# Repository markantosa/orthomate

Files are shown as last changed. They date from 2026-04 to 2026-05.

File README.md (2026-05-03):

# EPD 3D G6 — Orthomate

Battery-powered adaptive orthopedic insole controller. Redistributes plantar pressure in real-time using three micro linear stepper actuators driven by force sensor feedback. Includes a BLE companion Android app for live monitoring.

> **🏆 Winner — Top Course Project, EPD 3D Exhibition April 2026**

## Hardware at a glance

| Component | Detail |
|---|---|
| MCU | ESP32-C6 SuperMini |
| Stepper drivers | 3× TMC2209 (STEP/DIR mode, ENN hardwired LOW on PCB) |
| Actuators | 3× micro linear bipolar stepper |
| Pressure sensors | 4× FSR (R1 1kΩ + C 100nF RC filter per channel, R2 10kΩ pull-down) |
| Display | 0.91" OLED (SSD1306, I2C) |
| Charger | TP4056 Type-C |
| Boost converter | XL6009 → 5 V system rail |
| Battery | 1S LiPo 2000–3000 mAh |
| User input | 1× momentary mode button |
| BLE | NimBLE-Arduino 2.5.0 — advertises as `EPD3DG6` |

## PCB placement

Orthomate uses two custom PCBs that work together inside a modified shoe:

**Controller PCB** — mounts in a controller module. Houses the ESP32-C6, three TMC2209 stepper drivers, TP4056 charger, XL6009 boost converter, and the 20-pin connector (J9) to the insole. The LiPo battery sits alongside it.

**Insole PCB** — sits directly underfoot inside the shoe. Hosts the three FSR pressure-sensing zones (metatarsal, arch, calcaneus) and the three micro linear stepper actuator assemblies. The actuators extend upward to redistribute localised plantar pressure. Connects back to the controller PCB via a 20-pin ribbon/wire harness.

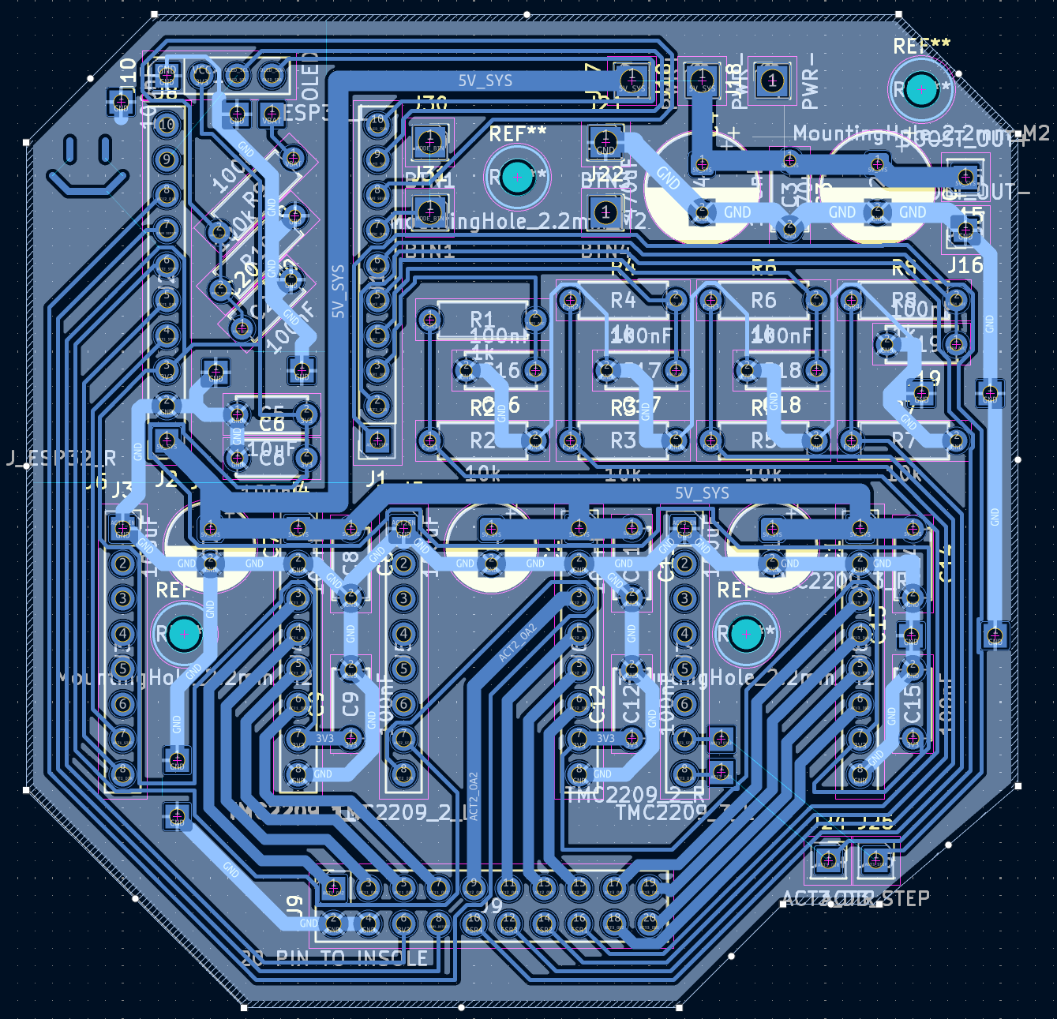
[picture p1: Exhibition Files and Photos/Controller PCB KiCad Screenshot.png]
Controller PCB
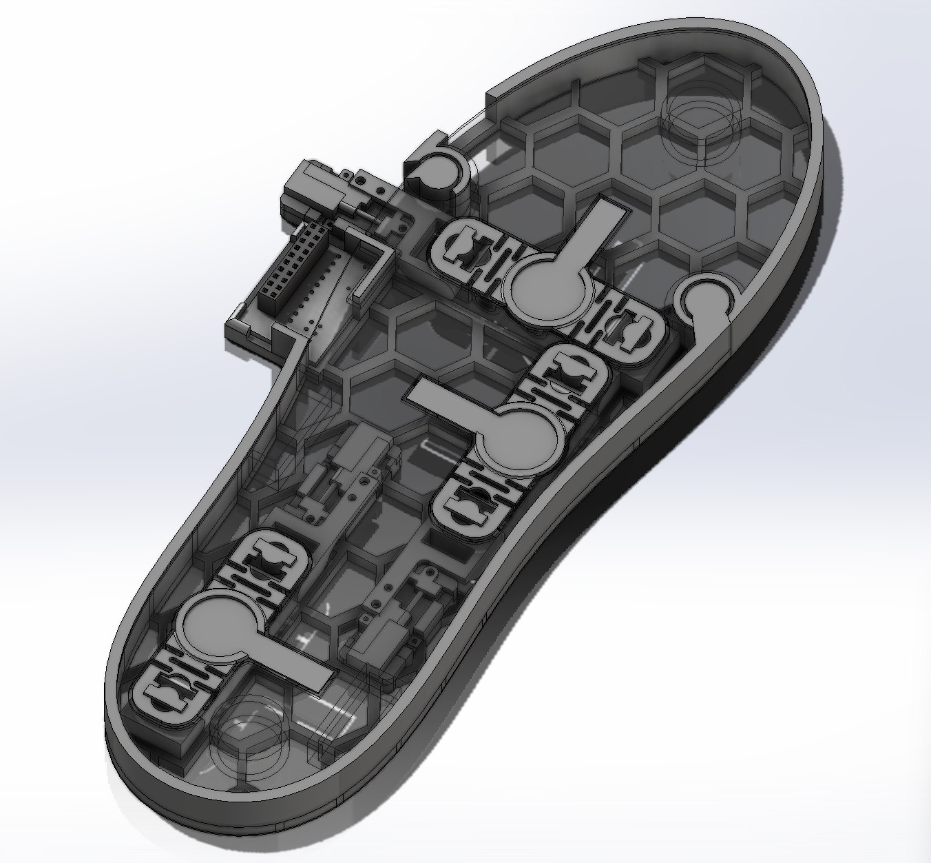
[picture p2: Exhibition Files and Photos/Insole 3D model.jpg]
Insole 3D Model
 

## Exhibition highlights

### Final product

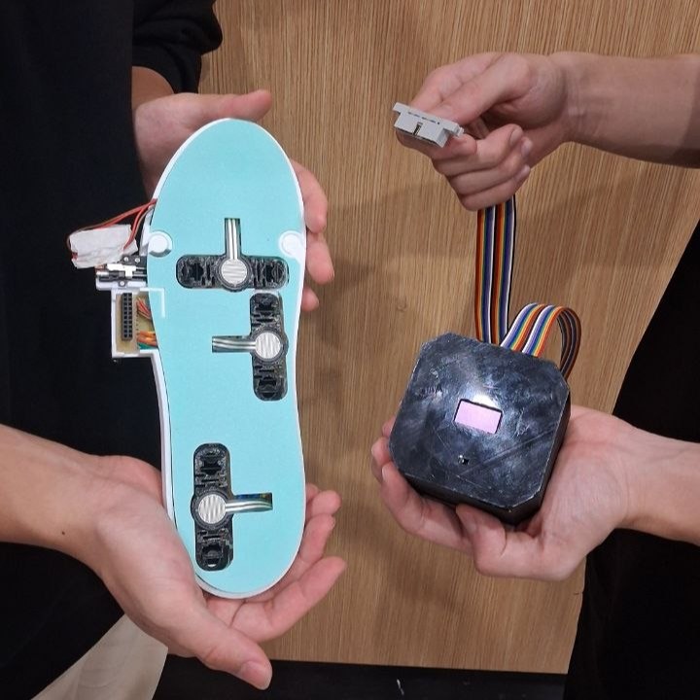
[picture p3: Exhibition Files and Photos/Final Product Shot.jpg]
Final Product Shot


### ANSYS stress analysis

Stress Analysis

### Exhibition day

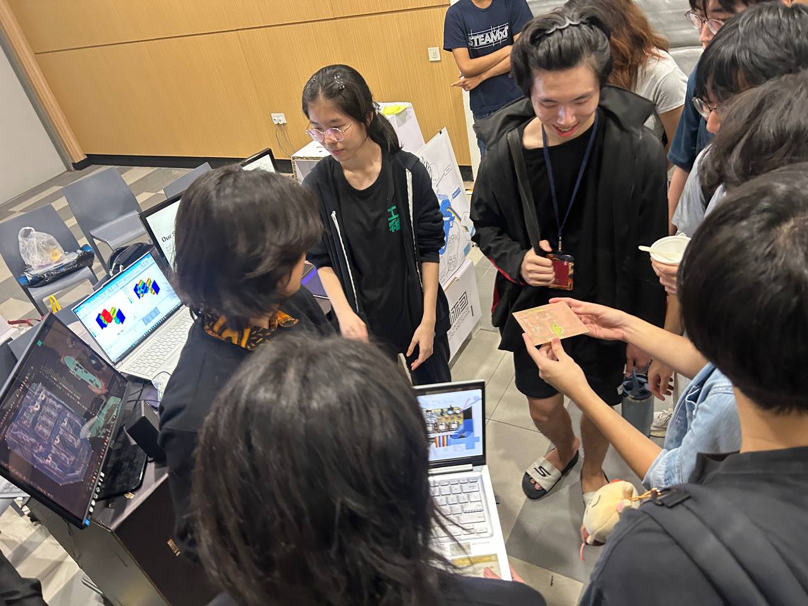
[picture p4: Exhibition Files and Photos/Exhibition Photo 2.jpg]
Exhibition Booth
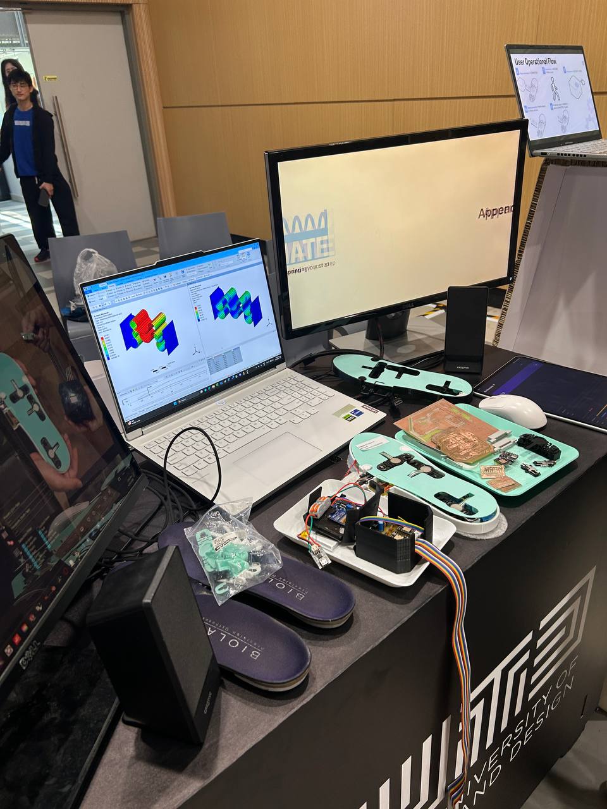
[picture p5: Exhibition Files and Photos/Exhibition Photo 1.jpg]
Team at Exhibition
 

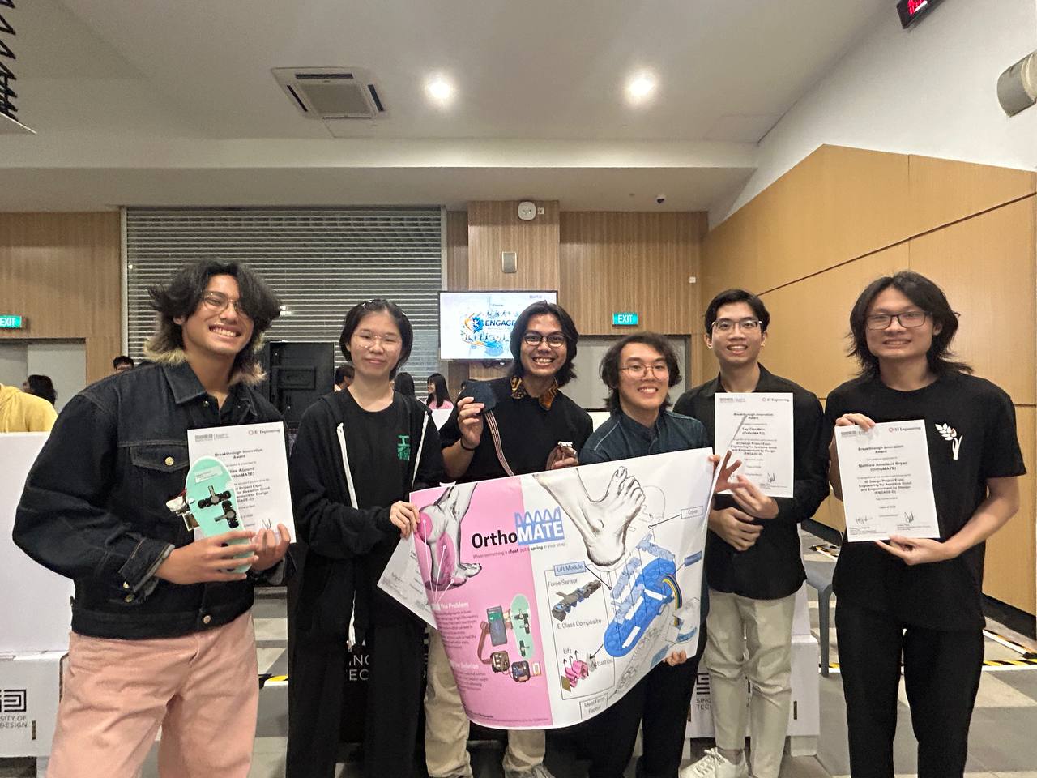
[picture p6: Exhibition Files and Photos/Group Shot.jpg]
Group Shot


### Poster

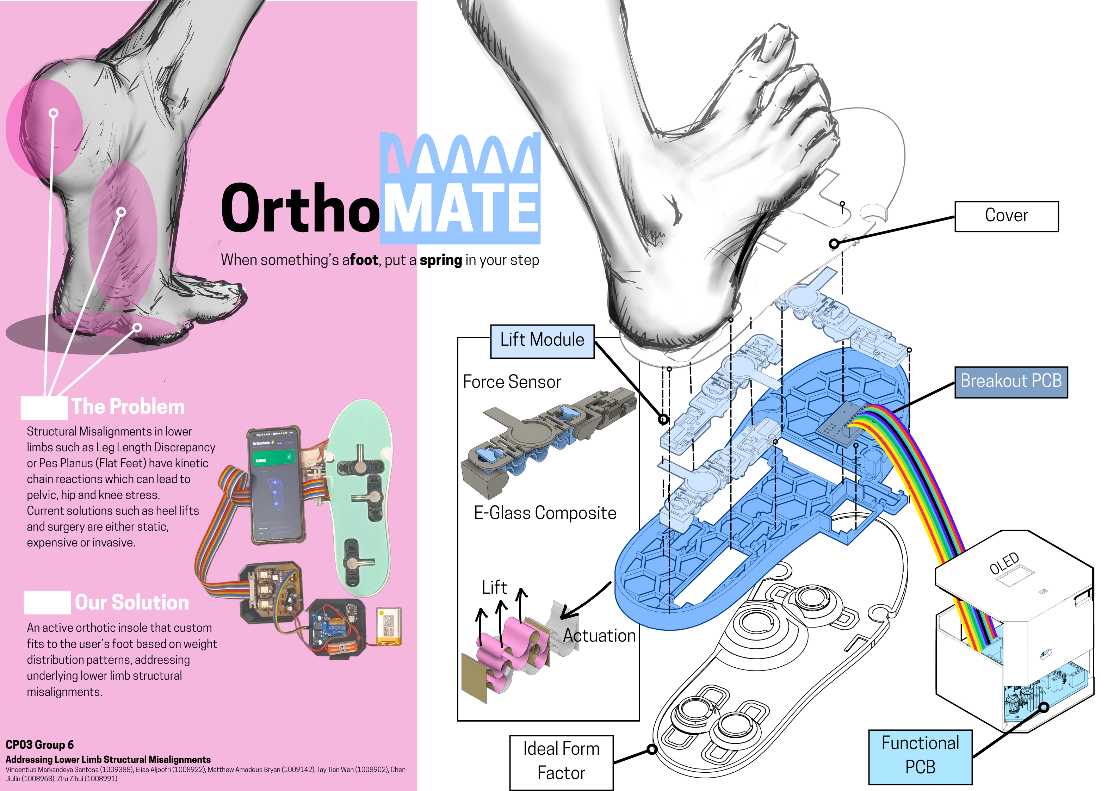
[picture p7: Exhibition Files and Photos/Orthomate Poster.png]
Orthomate Poster


### Downloadable resources

- [Orthomate Final Slides (PDF)](Exhibition%20Files%20and%20Photos/Orthomate%20Final%20Slides.pdf)
- [Orthomate Poster (PDF)](Exhibition%20Files%20and%20Photos/Orthomate%20Poster.pdf)

## Repository structure

```
orthomate/
├── Electronics Reference.txt           # Hardware design spec (v6.0)
├── BOM.txt                             # Bill of materials
├── firmware/
│   ├── main/                           # Full operational firmware (PlatformIO)
│   │   ├── platformio.ini
│   │   └── src/main.cpp
│   ├── ARDUINO IDE MAIN/               # Arduino IDE version of the full firmware
│   │   └── EPD3DG6_Main/EPD3DG6_Main.ino
│   ├── ARDUINO IDE APP TEST/           # Minimal Arduino IDE sketch for BLE app testing
│   │   └── sketch_apr14a/sketch_apr14a.ino
│   ├── stepper_test/                   # Single-axis stepper back-and-forth smoke test
│   ├── homing_test/                    # Blind homing: retract to min, extend to 12 mm
│   ├── button_test/                    # Button + OLED input test
│   └── oled_test/                      # OLED display test
├── android_app/                        # Kotlin/Compose BLE companion app
│   └── app/src/main/AndroidManifest.xml
├── Controller PCB KiCad Files/         # KiCad schematic + layout for controller PCB
├── Controller PCB Iterations/          # Gerber files from each revision (V2–V5)
├── Insole PCB KiCad Files/             # KiCad schematic + layout for insole PCB
├── Insole PCB Iterations/              # Gerber files from each revision
├── Exhibition Files and Photos/        # Exhibition media, poster, and slides
└── docs/
    ├── FIRMWARE_MAIN.md                # Detailed firmware walkthrough
    ├── FLASH_GUIDE.md                  # PlatformIO build & upload instructions
    ├── ANDROID_APP_GUIDE.md            # Android app build & sideload instructions
    └── TMC2209_CURRENT_TUNING.md
```

## Firmware — operational logic

The main firmware (`firmware/main/`) implements a full fitting cycle driven by one button:

```
DISCONNECTED ──[plug in]──► CONNECTED ──[btn]──► MEASURING
                                                      │ (auto)
                                                  MEASURED ──[btn]──► ACTUATING
                                                                           │ (auto)
                                                                         DONE ──[unplug]──► DISCONNECTED
                                                                         (insole retains shape)

On next plug-in with actuators extended:  DISCONNECTED ──► HOMING ──► CONNECTED
```

| Mode | Behaviour |
|---|---|
| **CONNECTED** | Idle; shows battery %, BLE status on OLED |
| **MEASURING** | Reads all 4 FSR channels, 7-sample median filter, computes relative load fractions |
| **ACTUATING** | Drives each actuator inversely proportional to region load — lowest load = largest extension |
| **DONE** | Holds position; unplug to use insole as-is |
| **HOMING** | Auto-triggered on reconnect when actuators are extended; retracts all to home |

Extension formula: $ext_i \propto (1 - r_i)$ where $r_i = F_i / \sum F$

## BLE — Android companion app

The ESP32 advertises a GATT service and notifies a JSON payload at ~4 Hz:

```json
{"fsr1": 42, "fsr2": 18, "fsr3": 75, "mode": "MEASURING", "batt": 67}
```

| BLE field | Value |
|---|---|
| Device name | `EPD3DG6` |
| Service UUID | `4fa0c560-78a3-11ee-b962-0242ac120002` |
| Characteristic UUID | `4fa0c561-78a3-11ee-b962-0242ac120002` (NOTIFY + READ) |
| Notify rate | ~4 Hz (every 250 ms) |
| MTU | 185 bytes |

The Android app (`android_app/`) displays real-time FSR forces as animated colour circles, current mode, battery %, and BLE status. See [docs/ANDROID_APP_GUIDE.md](docs/ANDROID_APP_GUIDE.md) for build and install instructions.

## GPIO assignment (ESP32-C6 SuperMini, Hardware Ref v6.0)

| GPIO | Function |
|---|---|
| 0 | FSR1 METATARSAL (ADC, 11 dB attenuation) |
| 1 | FSR2 ARCH (ADC, 11 dB attenuation) |
| 2 | FSR3 CALCANEUS (ADC, 11 dB attenuation) |
| 3 | FSR4 AUX (ADC, 11 dB attenuation) |
| 4 | MODE\_BUTTON (INPUT\_PULLUP) — boot-safe |
| 5 | VBAT\_SENSE (ADC1 ch5, 11 dB attenuation, 1:2 divider) |
| 6 | OLED SCL (I2C) |
| 7 | OLED SDA (I2C) |
| 14 | ACT3\_DIR ⚠ dead channel (stepper motor pad detached) |
| 15 | CONN\_DETECT (INPUT\_PULLDOWN) |
| 16 | ACT2\_STEP (arch actuator) |
| 17 | ACT2\_DIR (arch actuator) |
| 18 | ACT3\_STEP ⚠ dead channel (stepper motor pad detached) |
| 19 | ACT1\_DIR |
| 20 | ACT1\_STEP |

## Quick start

- **Flash firmware:** [docs/FLASH_GUIDE.md](docs/FLASH_GUIDE.md)
- **Install Android app:** [docs/ANDROID_APP_GUIDE.md](docs/ANDROID_APP_GUIDE.md)
- **Firmware internals:** [docs/FIRMWARE_MAIN.md](docs/FIRMWARE_MAIN.md)

## Design rules

- Charging and actuator operation are **mutually exclusive** — never simultaneous.
- Never start all 3 motors simultaneously — stagger motor starts by 75 ms.
- Sample FSRs only when motors are idle; use 7-sample median filtering with 4 ms settling per sample.
- ADC attenuation must be set to **11 dB** (`ADC_11db`) on all analog pins for correct readings at the operating voltage range.
- VBAT < 3.35 V → disable actuators; VBAT < 3.5 V → show low battery warning.
- OLED updates are content-cached — only redraws when text changes (prevents I2C writes during motor current spikes).

## License

MIT — see [LICENSE](LICENSE)

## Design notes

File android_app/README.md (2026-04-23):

# Orthomate ⚡
**Adaptive Insole System with AI Analysis**

Orthomate is an intelligent orthotic system that combines real-time pressure sensing, automated physical actuation, and AI-powered foot health analysis. The system consists of a smart insole (ESP32-C6 firmware) and this Android companion application.

---

## 🚀 Features

- **Real-time Pressure Mapping**: Visualizes foot pressure distribution using a dynamic heat-map and precise percentage bars.
- **Gemini 2.5 AI Analysis**: Integrates with Google's Gemini 2.5 Flash model to provide personalized insights into foot posture, health considerations, and practical stretches.
- **BLE Control Center**: Manage hardware states (Measuring, Actuating, Homing) and send commands directly to the insole via Bluetooth Low Energy.
- **Snapshot Memory**: Automatically saves the last measurement session for offline review and AI analysis.
- **Modular Architecture**: Clean, industry-standard codebase split into dedicated layers for Data, UI, and Logic.

---

## 🛠️ Setup Instructions

### 1. Prerequisites
- Android Studio Panda 4.
- A Google Gemini API Key from [Google AI Studio](https://aistudio.google.com/).

### 2. API Key Configuration
For security, the API key is **not** stored in the repository. You must add it locally:
1. Open the project in Android Studio.
2. Locate (or create) the `local.properties` file in the root directory.
3. Add the following line:
   ```properties
   gemini.api.key=YOUR_ACTUAL_API_KEY_HERE
   ```
4. Perform a **Gradle Sync** to allow the app to bake the key into the build.

### 3. Build & Run
- Connect an Android device or start an emulator.
- Go to `Build > Build Bundle(s) / APK(s) > Build APK(s)` for a test version.
- Or simply click the **Run** icon (Green Play button) in Android Studio.

---

## 📂 Project Structure

- **`com.epd3dg6.bleapp.data`**:
    - `BleConstants`: UUIDs and command bytes for hardware communication.
    - `Models`: Data classes for sensor readings and connection states.
    - `GeminiApi`: Retrofit interface for the Gemini 2.5 Flash API.
- **`com.epd3dg6.bleapp.ui`**:
    - `MainScreen`: The primary layout orchestrator.
    - `Components`: Reusable UI elements (Heatmap, FsrBars, Cards).
    - `Theme`: Custom dark-mode color scheme and styling.
- **`MainActivity.kt`**: Handles Bluetooth lifecycle, permissions, and top-level app logic.

---

## 🦶 How to Use

1. **Connect**: Power on the Orthomate insole and tap "Connect" in the app.
2. **Monitor**: Watch the live pressure map as you stand or walk.
3. **Capture**: Tap "Capture" (or trigger from hardware) to save a snapshot of your pressure distribution.
4. **Analyse**: Tap "Analyse with Gemini 2.5" to get AI insights based on your specific foot profile.
5. **Adjust**: Use the Home/Actuate controls to physically reshape the insole based on the data.

---

## 🛡️ Security Note
This project uses `.gitignore` to protect sensitive files like `local.properties` and auto-generated build files. Always ensure your API keys are never committed to version control.

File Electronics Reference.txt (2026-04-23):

# 🔧 Orthomate

## Hardware Design Reference (FINAL)

### **Revision V6.0 — ENN hardwired, OLED GPIO6/7, VBAT GPIO15, new J9 connector layout**

---

# 1. System Overview

Battery-powered adaptive orthopedic insole controller.

### Insole:

* 3× micro linear bipolar stepper actuators
* 4× FSR pressure sensors

### Controller:

* ESP32-C6 SuperMini (header-mounted)
* 3× TMC2209 (STEP/DIR mode, header-mounted)
* FSR analog front-end
* TP4056 Type-C charging module
* XL6009 boost converter → 5V system rail
* **0.91" OLED display (I2C)**

---

# 2. Power Architecture (MANDATORY)

```
3.7V LiPo
  │
  └── TP4056
         │
         └── VBAT (3.0–4.2V)
                │
                └── XL6009 boost
                       │
                       └── 5V_SYS
                              ├── ESP32 (VIN / 5V)
                              └── TMC2209 VM (x3)
```

---

## Rails

| Rail | Voltage  | Notes |
| --- | --- | --- |
| VBAT | 3.0–4.2V | Battery |
| 5V_SYS | 5V | Boost output  |
| 3V3 | 3.3V | ESP32 onboard |
| GND | 0V | Common |

---

## Critical Rule

> ESP32 MUST be powered from **5V_SYS**, not LiPo directly

---

# 3. Charging Behavior

TP4056 is **NOT power-path managed**

### Rule:

> Charging and actuation must NOT occur simultaneously

### Firmware:

```
STEPPER_ENN = HIGH (disable drivers)
```

---

# 4. Power Stability

### XL6009 Output (on PCB)

* 470µF bulk
* * optional 470–1000µF
* 100nF ceramic

### ESP32

* 10µF
* 100nF

### Per TMC2209

* 100µF (VM)
* 100nF (VM)
* 100nF (VIO)

---

# 5. Battery Monitoring

```
VBAT ── 100k ──+──→ GPIO5 (ADC1 ch5)
               |
              100k
               |
              GND
```

---

# 6. FINAL ESP32-C6 PIN ASSIGNMENT (UPDATED)

## ⚠️ Constraint-aware mapping (SuperMini breakout)

---

## Analog Inputs (ADC-safe zone)

| Function | GPIO  |
| --- | ----- |
| FSR1 | GPIO0 |
| FSR2 | GPIO1 |
| FSR3 | GPIO2 |
| FSR4 | GPIO3 |

---

## VBAT Monitor

| Function | GPIO  | Note |
| --- | ----- | --- |
| VBAT_SENSE | GPIO5 | ADC1 channel 5 — fully ADC-capable |

---

## Stepper Control

| Actuator | STEP | DIR |
| --- | --- | --- |
| ACT1 | GPIO20 | GPIO19 |
| ACT2 | GPIO18 | GPIO14 |
| ACT3 | GPIO16 | GPIO17 |

---

## ENN (Shared Enable)

All TMC2209 ENN pins are **hardwired to GND on the PCB** (always enabled).
No firmware GPIO required.

---

## OLED (I2C)

| Signal | GPIO  |
| --- | ----- |
| SDA | GPIO7 |
| SCL | GPIO6 |

---

## User Input

| Function | GPIO |
| --- | --- |
| MODE_BTN | GPIO4  |
| CONN_DETECT  | GPIO15 |

---

## ⚠️ Pin Notes (IMPORTANT)

| Pin | Note |
| --- | --- |
| GPIO4 | Strapping pin → button must NOT be held at boot |
| GPIO5 | VBAT_SENSE — ADC1 ch5; 100k/100k divider to VBAT |
| GPIO6 | OLED SCL — strapping-safe, pull-up OK |
| GPIO7 | OLED SDA (previously STEPPER_ENN) |
| GPIO15 | CONN_DETECT — INPUT_PULLDOWN (internal ~45k); loopback via insole 10k; no external pulldown needed |
| GPIO16/17 | UART default → now used for STEP/DIR |
| GPIO8 | Avoid (often onboard LED) |

---

# 7. Stepper Driver Architecture

## TMC2209 ×3

### Power

* VM → 5V_SYS
* VIO → 3V3
* GND → GND

### Control

* STEP / DIR → ESP32
* ENN → **GND (hardwired on PCB)** — always enabled; no firmware GPIO required

### Motor Outputs

* OA1/OA2 → Coil A
* OB1/OB2 → Coil B

---

## Debug Pads (REQUIRED)

Expose:

* PDN_UART
* DIAG

---

# 8. FSR Analog Front-End

Per channel:

```
3V3
 |
FSR
 |
 +---- RAW ---- 1k ----> ADC (GPIO0–3)
 |
10k
 |
GND
```

At ADC:

* 100nF → GND

---

# 9. OLED Display

| OLED | ESP32  |
| ---- | --- |
| VCC  | 3V3 |
| GND  | GND |
| SDA  | GPIO7  |
| SCL  | GPIO6  |

---

# 10. Connector Definition

## J_MAIN (20-pin)

**Footprint:** `Connector_Generic:Conn_02x10_Odd/Even`
(Row A = odd pins 1/3/5…19, Row B = even pins 2/4/6…20)

### Physical layout

| Row | Pin A (odd) | Signal A | Signal B | Pin B (even) |
| --- | --- | --- | --- | --- |
| 1 | 1 | ACT1_OA2 | GND | 2 |
| 2 | 3 | ACT1_OA1 | GND | 4 |
| 3 | 5 | ACT1_OB1 | 3V3 | 6 |
| 4 | 7 | ACT1_OB2 | CONN_DETECT  | 8 |
| 5 | 9 | ACT2_OA2 | FSR4 | 10 |
| 6 | 11 | ACT2_OA1 | FSR3 | 12 |
| 7 | 13 | ACT2_OB1 | FSR2 | 14 |
| 8 | 15 | ACT2_OB2 | FSR1 | 16 |
| 9 | 17 | ACT3_OA2 | ACT3_OB2 | 18 |
| 10  | 19 | ACT3_OA1 | ACT3_OB1 | 20 |

### Per-pin reference

### Loopback detect circuit

```
Controller PCB:         Insole PCB:
pin 6 (3V3) ──────────── 10k ──── pin 8 (CONN_DETECT)
                                        │
                                   GPIO15 (INPUT_PULLDOWN, ~45k internal)
                                        │
                                       GND
```

* Unplugged → GPIO5 pulled LOW by internal pulldown → CONN_DETECT = 0
* Plugged in → 3V3 through insole 10k + internal ~45k divider → **V_GPIO5 ≈ 2.7V** → CONN_DETECT = 1
* No external pulldown resistor needed on controller PCB
* Insole only needs one 0402 10k between pin 1 and pin 2

### Per-pin reference

| Pin | Signal | Notes |
| --- | --- | --- |
| 1 | ACT1_OA2 | TMC2209 OA2 → ACT1 coil A− |
| 2 | GND | Power return |
| 3 | ACT1_OA1 | TMC2209 OA1 → ACT1 coil A+ |
| 4 | GND | Power return |
| 5 | ACT1_OB1 | TMC2209 OB1 → ACT1 coil B+ |
| 6 | 3V3 | Source for loopback detect; drives insole 10k |
| 7 | ACT1_OB2 | TMC2209 OB2 → ACT1 coil B− |
| 8 | CONN_DETECT  | → GPIO5 (INPUT_PULLDOWN); HIGH = insole connected |
| 9 | ACT2_OA2 | TMC2209 OA2 → ACT2 coil A− |
| 10  | FSR4 | → GPIO3 (ADC) |
| 11  | ACT2_OA1 | TMC2209 OA1 → ACT2 coil A+ |
| 12  | FSR3 | → GPIO2 (ADC) |
| 13  | ACT2_OB1 | TMC2209 OB1 → ACT2 coil B+ |
| 14  | FSR2 | → GPIO1 (ADC) |
| 15  | ACT2_OB2 | TMC2209 OB2 → ACT2 coil B− |
| 16  | FSR1 | → GPIO0 (ADC) |
| 17  | ACT3_OA2 | TMC2209 OA2 → ACT3 coil A− |
| 18  | ACT3_OB2 | TMC2209 OB2 → ACT3 coil B− |
| 19  | ACT3_OA1 | TMC2209 OA1 → ACT3 coil A+ |
| 20  | ACT3_OB1 | TMC2209 OB1 → ACT3 coil B+ |

---

# 11. PCB Zoning

## Zone A — Power

* LiPo
* TP4056
* XL6009
* bulk caps

## Zone B — Stepper

* TMC2209
* motor outputs

## Zone C — Logic + Analog

* ESP32
* FSR circuits
* OLED

> Keep Zone C far from boost + motors 

---

# 12. Ground Strategy

**Trunk + Branch**

* Battery GND = origin
* Separate:

  * Power return
  * Logic return
  * Analog return

> NEVER mix motor return with analog ground 

---

# 13. Routing Priorities

1. Power
2. Motor outputs
3. STEP/DIR
4. Analog
5. I2C

---

## Trace Widths

| Type | Width |
| --- | --- |
| Power | 1.5–2.0 mm  |
| Motor | 0.8–1.2 mm  |
| Digital | 0.25–0.4 mm |
| Analog  | 0.25–0.4 mm |

---

# 14. Boost Layout Rules

* Keep far from analog
* Minimize loop area
* Thick traces
* Treat as **noise source**

---

# 15. Firmware Interaction Rules

## Motion

* Do NOT start all motors at once
* Delay 50–100 ms

## ADC

* Sample when motors idle OR median filter

## OLED

* 5–10 Hz update
* Avoid switching spikes

---

# 16. Bring-Up Sequence

1. Power only
2. Validate ADC + 3.3V
3. Test OLED
4. Test 1 driver
5. Scale

---

# 17. Risks & Mitigation

## R1 — FSR Noise

* RC filter
* zoning

## R2 — Power instability

* bulk caps

## R3 — Charging conflict

* firmware lockout

## R4 — Boot issues (NEW)

* avoid pulling GPIO4 during boot

---

# 18. Battery Recommendation

* Minimum: 1000mAh
* Recommended: 2000–3000mAh
* Preferred: ≥3000mAh

---

# 19. Final Summary

* 1S LiPo
* TP4056
* XL6009 → 5V_SYS
* ESP32-C6 (limited GPIO map)
* 3× TMC2209
* 4× FSR (ADC0–3)
* OLED (GPIO9/15)
* Shared ENN (GPIO7)
* Button on GPIO4 (boot-safe usage)
* Connector detect on GPIO5 (INPUT_PULLDOWN)
* Single-layer PCB

---

# 🧠 What changed (important insight)

This new version is:

* **pin-constrained but valid**
* **boot-safe (if used correctly)**
* **still routable single-layer (with good placement)**

---

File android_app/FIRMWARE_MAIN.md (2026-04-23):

# Firmware — `firmware/main` Explained

**File:** `firmware/main/src/main.cpp`
**Hardware ref:** v6.0

---

## 1. What the firmware does

Single-session insole fitting cycle:

1. Detect insole connector
2. Measure foot pressure distribution (FSR sensors)
3. Compute how far each actuator should extend
4. Drive the three stepper actuators to those positions
5. Hold position until the user triggers retract

Everything is driven by one button and one connector-detect pin.

---

## 2. State machine

```
DISCONNECTED ──[plug in, pos=home]──► CONNECTED
DISCONNECTED ──[plug in, pos≠0]────► HOMING ──┐
                                               │
CONNECTED    ──[btn #1]────────────► MEASURING ◄─┘
                                       │
                                    MEASURED
                                       │ [btn #2]
                                    ACTUATING
                                       │
                                      DONE  ──[unplug]──► DISCONNECTED
                                             (insole retains shape)
any state    ──[unplug]────────────► DISCONNECTED
```

**Full user flow:**
1. Plug in connector → CONNECTED (or HOMING if actuators were extended)
2. Press button → measure → press button → actuate → DONE
3. Unplug connector → insole retains its shape, use as-is
4. To reshape: plug in → auto-home → back to CONNECTED → repeat

States are an `enum State` (`ST_DISCON`, `ST_CONN`, `ST_MEASURING`, `ST_MEASURED`, `ST_ACTUATING`, `ST_DONE`, `ST_HOMING`). The main loop polls at ~20 Hz (`delay(50)` at the bottom of `loop()`).

Two transitions fire outside the switch block and override any state:
- **Unplug** → immediately sets `PIN_ENN` HIGH (disables drivers), transitions to `ST_DISCON`. `gPos[]` is **not reset** — position is remembered so homing is triggered correctly on the next reconnect.
- **Hard low-battery** (`VBAT < VBAT_CUTOFF = 3.35 V`) → sets `PIN_ENN` HIGH, blocks the loop for 5 s, returns without advancing state.

**Reconnect logic:**
```cpp
bool needsHome = false;
for (int i = 0; i < 3; i++) if (gPos[i] != 0) { needsHome = true; break; }
gState = needsHome ? ST_HOMING : ST_CONN;
```
If any actuator has a non-zero tracked position, the firmware goes to `ST_HOMING` before allowing a new cycle.

---

## 3. Connector detect

**Circuit:**
```
J_MAIN pin 6 (3V3) ── insole 10 kΩ ──► pin 8 (CONN_DETECT) ──► GPIO15
                                                                     │
                                                           INPUT_PULLDOWN (~45 kΩ internal)
                                                                     │
                                                                    GND
```

**Logic:**
- Unplugged: GPIO15 pulled LOW by internal ~45 kΩ → `connPresent() = false`
- Plugged in: 3.3 V through insole 10 kΩ + internal 45 kΩ divider → V ≈ 2.7 V → `connPresent() = true`
- No external resistor needed on the controller PCB

---

## 4. FSR measurement

**Function:** `doMeasure()`

### 4.1 ADC sampling

Each FSR channel is read with a 7-sample insertion-sort **median filter** (`medianADC()`):

```cpp
// ADC_SAMPLES = 7, 4 ms apart
// Returns the middle value of the sorted array
return buf[ADC_SAMPLES / 2];
```

The median (not mean) is used to reject single-sample spikes from motor switching noise or contact bounce.

### 4.2 Relative load fractions

Raw ADC counts (0–4095, 12-bit) are normalised:

$$r_i = \frac{F_i}{\sum_{j=0}^{3} F_j}, \quad \sum r_i = 1$$

```cpp
float sum = raw[0] + raw[1] + raw[2] + raw[3];
if (sum < 1.0f) sum = 1.0f;   // guard: zero load (sensors floating/open)
for (int i = 0; i < 4; i++) gRelLoad[i] = raw[i] / sum;
```

FSR4 (`GPIO3`) contributes to the normalisation sum but has no actuator — it acts as an auxiliary pressure reference (rear heel).

### 4.3 Extension target calculation

The corrective logic is **inverse**: the zone bearing the *least* load gets the *most* extension (raises that zone to redistribute weight).

$$\text{ext}_i = 1 - r_i, \quad i \in \{1,2,3\}$$

$$\text{target\_steps}_i = \lfloor \text{ext}_i \times \texttt{MAX\_EXT\_STEPS} \rfloor$$

```cpp
float ext = 1.0f - gRelLoad[i];
if (ext < EXT_DEADBAND) ext = 0.0f;       // 8% deadband — suppress noise
ext = constrain(ext, 0.0f, 1.0f);
gTarget[i] = (int32_t)(ext * MAX_EXT_STEPS);
```

**Example:**

| FSR | Raw ADC | r_i  | ext = 1−r_i | target steps (MAX=400) |
|-----|---|---|---|---|
| 1 | 1200 | 0.40 | 0.60 | 240 |
| 2 | 600 | 0.20 | 0.80 | 320 |
| 3 | 900 | 0.30 | 0.70 | 280 |
| 4 | 300 | 0.10 | (no ACT) | — |
| Σ | 3000 | 1.00 | | |

FSR2 has the lowest load → ACT2 extends the most.

**Deadband** (`EXT_DEADBAND = 0.08`): if a computed extension fraction is less than 8%, it is zeroed. This prevents tiny actuator movements from wearing the mechanism on near-uniform pressure distributions.

---

## 5. Battery monitoring

**Circuit:** 1:2 resistor divider (100 kΩ / 100 kΩ) on VBAT → GPIO5 (ADC1 ch5)

$$V_{\text{BAT}} = \frac{\text{ADC count}}{4095} \times 3.3\,\text{V} \times 2$$

$$V_{\text{BAT}} = \frac{\text{ADC count}}{4095} \times 3.3\,\text{V} \times 2$$

```cpp
float vadc = (medianADC(PIN_VBAT) / 4095.0f) * 3.3f;
return vadc * 2.0f;
```

| Threshold | Value | Action |
|---|---|---|
| `VBAT_WARN` | 3.50 V | Show "! LOW BATTERY" warning on OLED in `ST_CONN` |
| `VBAT_CUTOFF` | 3.35 V | Disable motors, block loop for 5 s, require charge |
| `VBAT_NOISE` | 0.50 V | Ignore reads below this (no battery connected during dev) |

The cutoff check runs **before** the state machine in every loop iteration — it cannot be bypassed by state transitions.

**ADC configuration (critical):** The ESP32-C6 default ADC attenuation is `ADC_0db` (~0–0.8 V). The VBAT sense node sits at ~1.85 V at 3.7 V nominal charge. Without explicit attenuation, all readings saturate and return ~0%.

```cpp
// setup()
analogReadResolution(12);                               // 0–4095
analogSetPinAttenuation(PIN_VBAT, ADC_11db);            // 0–3.3 V full-scale
Serial.printf("[ADC] VBAT raw sanity: %d\n", analogRead(PIN_VBAT));
```

The same `ADC_11db` setting applies to all FSR pins (GPIO 0–3) to cover pressures up to the divider rail voltage.

---

## 6. Actuation

**Function:** `doActuate()`

### 6.1 Step generation

`driveSteps(step_pin, dir_pin, steps)`:
- Positive `steps` → `DIR = HIGH` (extend)
- Negative `steps` → `DIR = LOW` (retract)
- Each pulse: `STEP = HIGH` for `STEP_PULSE_US = 5 µs`, then `LOW` for `STEP_DELAY_US = 1500 µs`
- Effective step rate: $\frac{1}{1505\,\mu s} \approx 664\,\text{Hz}$ → ~664 steps/s

At `MAX_EXT_STEPS = 400`, full extension takes:

$$t = \frac{400}{664} \approx 0.6\,\text{s per actuator}$$

### 6.2 Position tracking

`gPos[3]` tracks current step position from home (0 = fully retracted) for each actuator. `moveToTarget()` computes the delta and calls `driveSteps()` with only the required number of additional steps:

```cpp
int32_t delta = target - gPos[idx];
driveSteps(PIN_STEP[idx], PIN_DIR[idx], delta);
gPos[idx] = target;
```

This allows calling `doActuate()` or `retractAll()` at any time without needing to know the current physical position from scratch.

### 6.3 Stagger

Motors are driven **sequentially** with `ACT_STAGGER_MS = 75 ms` delay between each. This prevents current spikes from three simultaneous motor starts from destabilising the 5V_SYS rail.

### 6.4 ENN hold

After actuation, `PIN_ENN` remains LOW (drivers enabled). This maintains holding torque so actuators do not back-drive under body weight while the connector is still attached.

On **unplug**, ENN goes HIGH immediately (no current draw during use — the insole is self-contained). Position is mechanically retained by the self-locking lead screw mechanism.

ENN is set HIGH by:
- Connector unplug (any state)
- `retractAll()` completion (ST_HOMING)
- Low-battery cutoff

---

## 7. Button logic

`btnEdge()` returns `true` exactly **once** per physical button press:

```
falling edge detected (LOW) + !gLastBtn + Δt > BTN_DEBOUNCE_MS (30 ms)
```

- `PIN_BUTTON = GPIO4` is `INPUT_PULLUP` → LOW when pressed
- GPIO4 is a strapping pin; the button must **not** be held at boot or it forces the chip into download mode

---

## 8. BLE (Bluetooth Low Energy)

**Library:** `h2zero/NimBLE-Arduino @ ^2.1.0` (resolves to v2.5.0). NimBLE 1.4.x is **not compatible** with ESP32-C6 IDF 5.x — it fails with a missing `syscfg/syscfg.h` header. NimBLE 2.x bundles its own Mynewt stack and is IDF 5.x safe.

**Function:** `setupBLE()` — called once in `setup()`:

```cpp
NimBLEDevice::init("EPD3DG6");
NimBLEDevice::setMTU(185);
NimBLEServer* server = NimBLEDevice::createServer();
server->setCallbacks(new BleServerCallbacks());
server->advertiseOnDisconnect(true);     // auto-restart advertising after disconnect

NimBLEService* svc = server->createService(SVC_UUID);
gBleChar = svc->createCharacteristic(CHAR_UUID,
    NIMBLE_PROPERTY::READ | NIMBLE_PROPERTY::NOTIFY);
svc->start();

NimBLEAdvertising* adv = NimBLEDevice::getAdvertising();
adv->addServiceUUID(SVC_UUID);
adv->setName("EPD3DG6");
adv->enableScanResponse(true);
adv->start();
```

**UUIDs:**

| Item | UUID |
|---|---|
| Service | `4fa0c560-78a3-11ee-b962-0242ac120002` |
| Characteristic | `4fa0c561-78a3-11ee-b962-0242ac120002` |

**Notify payload:** JSON, sent every 250 ms when a client is connected:

```json
{"fsr1": 42, "fsr2": 18, "fsr3": 75, "mode": "MEASURING", "batt": 67}
```

- `fsr1–3`: relative FSR percentage (0–100), computed from `gRelLoad[]`
- `mode`: current state name string (`DISCONNECTED`, `CONNECTED`, `MEASURING`, `MEASURED`, `ACTUATING`, `DONE`, `HOMING`)
- `batt`: battery percentage (0–100), mapped from 3.3 V → 0% to 4.2 V → 100%

**Globals:**

```cpp
NimBLECharacteristic* gBleChar      = nullptr;  // characteristic handle
bool                   gBleConnected = false;    // true when client subscribed
uint32_t               gBleLastNotify = 0;       // millis() timestamp of last notify
float                  gLastVbat     = 0.0f;     // latest VBAT reading cached for notify
```

**Connection callbacks** (NimBLE 2.x API):

```cpp
void onConnect(NimBLEServer*, NimBLEConnInfo&)       { gBleConnected = true; }
void onDisconnect(NimBLEServer*, NimBLEConnInfo&, int) { gBleConnected = false; }
```

NimBLE 1.x used `NimBLEServerCallbacks::onConnect(NimBLEServer*)` without the `NimBLEConnInfo&` and reason integer — using the old signatures is a compile error on v2.x.

**`bleNotify(float vbat)`** formats the JSON and calls `gBleChar->setValue()` + `gBleChar->notify()`. It is called from `loop()` every 250 ms when `gBleConnected == true`:

```cpp
if (gBleConnected && (millis() - gBleLastNotify >= 250)) {
    bleNotify(vbat);
    gBleLastNotify = millis();
}
```

---

## 9. OLED display

**`showOLEDWithStatus(r1, r2)`** is the primary display function used throughout the state machine. It always appends a third row with battery % and BLE connection status:

```
Row 1: <state label>           e.g. "CONNECTED"
Row 2: <detail info>           e.g. "Press button"
Row 3: B:72% BLE:OK            or "B:72% BLE:--" when not connected
```

It internally calls `showOLED(r1, r2, statusRow)` which includes a **content cache** — no I2C transaction is issued if all three strings are unchanged from the previous call.

| State | Row 1 | Row 2 |
|---|---|---|
| ST_DISCON | DISCONNECTED | Plug in insole |
| ST_CONN (normal) | CONNECTED | Press button |
| ST_CONN (low batt) | ! LOW BATTERY | Charge now |
| ST_MEASURING | MEASURING... | Please wait |
| ST_MEASURED | MEASURED | Press to actuate |
| ST_ACTUATING | ACTUATING... | Please wait |
| ST_DONE | DONE | Unplug to use |
| ST_HOMING | HOMING... | Please wait |

The display is non-critical: `gOledOk` is checked at the start of every call. If no OLED is detected on boot, display calls are silently skipped.

I2C bus: SDA = GPIO7, SCL = GPIO6.

---

## 10. Key constants summary

| Constant | Value | Meaning |
|---|---|---|
| `MAX_EXT_STEPS` | 400 | Full extension travel in steps |
| `STEP_DELAY_US` | 1500 µs | Inter-step interval (sets motor speed) |
| `STEP_PULSE_US` | 5 µs | STEP pin HIGH width (TMC2209 min = 2 µs) |
| `ACT_STAGGER_MS` | 75 ms | Delay between sequential motor starts |
| `EXT_DEADBAND` | 0.08 | Minimum extension fraction before zeroing |
| `ADC_SAMPLES` | 7 | Median filter depth (must be odd) |
| `BTN_DEBOUNCE_MS` | 30 ms | Minimum time between accepted button edges |
| `VBAT_WARN` | 3.50 V | OLED warning threshold |
| `VBAT_CUTOFF` | 3.35 V | Hard motor disable threshold |
| `SVC_UUID` | `4fa0c560-...` | BLE service UUID |
| `CHAR_UUID` | `4fa0c561-...` | BLE characteristic UUID |

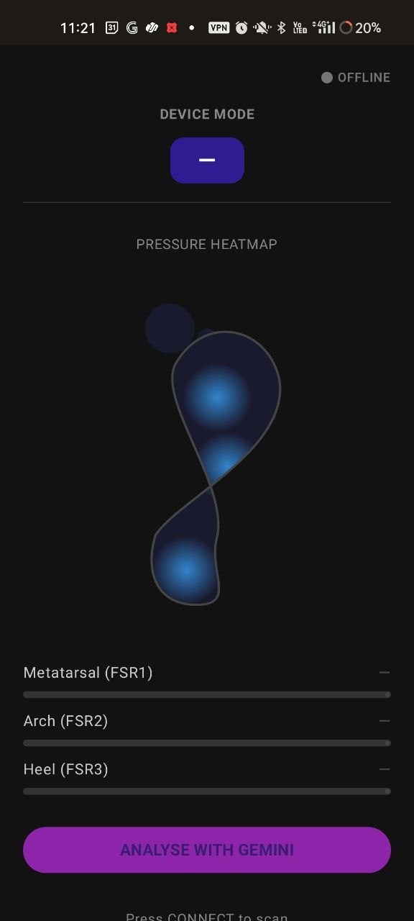
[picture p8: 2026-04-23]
android_app/for gemini/photo_6278394425092280044_y.jpg

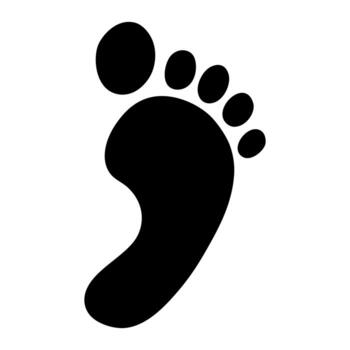
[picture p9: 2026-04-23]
android_app/for gemini/feet_002.jpg

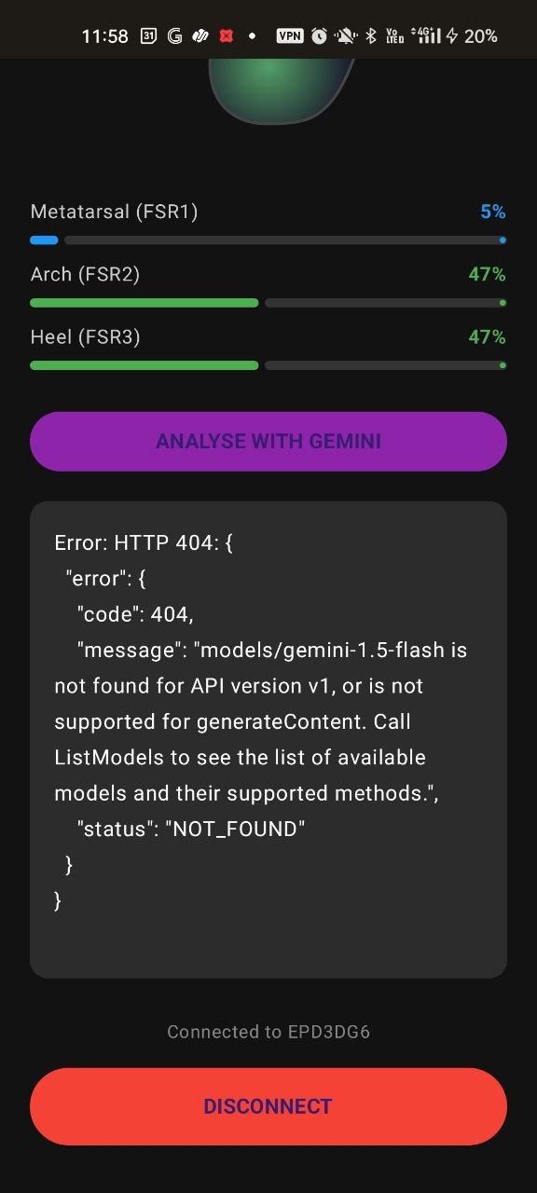
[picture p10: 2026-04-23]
android_app/for gemini/photo_6278394425092280059_y.jpg

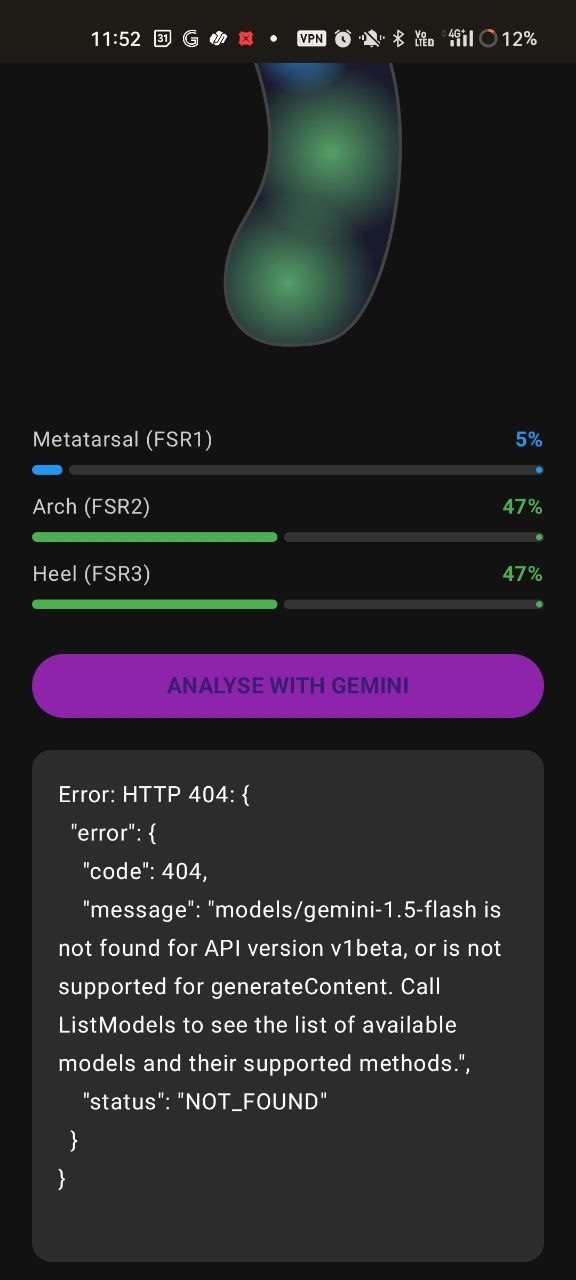
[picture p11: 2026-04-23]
android_app/for gemini/photo_6278394425092280055_y (1).jpg

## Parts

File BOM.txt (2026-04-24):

Complete BOM for the Orthomate system: **ESP32-C6 SuperMini + 3× TMC2209 + 4× FSR + 0.91" OLED + LiPo + TP4056 + XL6009**.

## PCB overview

Orthomate uses two custom PCBs:

**Controller PCB** — mounted in a housing at the rear of the shoe. Contains the ESP32-C6, three TMC2209 stepper driver modules, TP4056 charger, XL6009 boost converter, battery voltage divider, OLED connector, and the 20-pin connector (J9) linking to the insole. The LiPo battery sits in the same heel housing.

**Insole PCB** — sits directly underfoot inside the shoe. Hosts the four FSR pressure-sensing zones (metatarsal, arch, calcaneus, auxiliary) with their analog front-end filter networks, and provides mechanical mounting points for the three micro linear stepper actuator assemblies. Connects to the controller PCB via a 20-pin ribbon/wire harness through J9.

# Total BOM

## 1) Main modules

| Qty | Item | Notes |
| --: | --- | --- |
| 1 | **ESP32-C6 SuperMini** | Main MCU board |
| 3 | **TMC2209 stepper driver modules** | STEP/DIR mode, header-mounted |
| 1 | **0.91" OLED display** | I2C, SSD1306/SH1106 type |
| 1 | **TP4056 Type-C charging module**  | 1S LiPo charging/protection |
| 1 | **XL6009 boost converter module**  | Boost VBAT to 5V_SYS |
| 1 | **1S LiPo battery** | Recommended 2000–3000 mAh |

---

## 2) Sensors and actuators

| Qty | Item | Notes |
| --: | --- | --- |
| 4 | **FSR pressure sensors** | One per sensing zone  |
| 3 | **Micro linear bipolar stepper actuators** | Main insole actuators |

---

## 3) Passives

### Battery sensing divider

| Qty | Item | Value |
| --: | --- | --- |
| 2 | Resistor | **100 kΩ** |

### FSR analog front-end

Per channel: 1× FSR divider resistor, 1× series resistor, 1× filter capacitor. 

| Qty | Item | Value |
| --: | --- | --- |
| 4 | Resistor  | **10 kΩ**  |
| 4 | Resistor  | **1 kΩ** |
| 4 | Capacitor | **100 nF** |

### ESP32 local decoupling

| Qty | Item | Value |
| --: | --- | --- |
| 1 | Capacitor | **10 µF**  |
| 1 | Capacitor | **100 nF** |

### XL6009 output bulk / decoupling

| Qty | Item | Value |
| --: | --- | --- |
| 1 | Capacitor | **470 µF** |
| 1 | Capacitor | **470–1000 µF** |
| 1 | Capacitor | **100 nF** |

### Per TMC2209 local caps

Per driver: 1× 100 µF VM bulk, 1× 100 nF VM, 1× 100 nF VIO. 

| Qty | Item | Value |
| --: | --- | --- |
| 3 | Capacitor | **100 µF electrolytic** |
| 6 | Capacitor | **100 nF ceramic** |

---

## 4) Connectors and headers

| Qty | Item | Notes |
| --: | --- | --- |
| 1 | **20-pin main connector** | For power, FSRs, actuators |
| 2 | **Female header strips for ESP32-C6 SuperMini** | Pin-socket mounting on PCB |
| 3 | **Header sets for TMC2209 modules** | Module plug-in mounting |
| 1 | **LiPo connector** | Match your battery type |
| 1 | **OLED 4-pin header** | VCC, GND, SDA, SCL |

---

## 5) Recommended debug / service features

| Qty | Item | Notes |
| --: | --- | --- |
| 3 | **PDN_UART breakout pads** | One per TMC2209 |
| 3 | **DIAG breakout pads** | One per TMC2209 |
| 1 | **USB detect / charge detect connection** | For firmware lockout during charging |

---

# Component count summary

## Functional parts

* 1 ESP32-C6 SuperMini
* 3 TMC2209 modules
* 1 OLED
* 1 TP4056
* 1 XL6009
* 1 LiPo
* 4 FSRs
* 3 stepper actuators

## Resistors

* 2 × 100 kΩ
* 4 × 10 kΩ
* 4 × 1 kΩ

**Total resistors = 10**

## Capacitors

* 1 × 10 µF
* 1 × 470 µF
* 1 × 470–1000 µF
* 3 × 100 µF electrolytic
* 12 × 100 nF ceramic

**Total capacitors = 18**

---

# Grand total by line item type

If counted as individual physical components:

* **Major modules / devices:** 15

  * 1 ESP32
  * 3 TMC2209
  * 1 OLED
  * 1 TP4056
  * 1 XL6009
  * 1 LiPo
  * 4 FSR
  * 3 steppers

* **Passives:** 28

  * 10 resistors
  * 18 capacitors

* **Connectors / headers / interconnects:** depends on your exact PCB implementation, but realistically:

  * 1 main 20-pin connector
  * 2 ESP32 header strips
  * 3 TMC header sets
  * 1 OLED header
  * 1 battery connector

So your practical BOM is about **35–45 physical parts**, excluding PCB, wires, screws, spacers, and enclosure hardware.

---

# Minimal purchasing BOM

If you just want the parts to buy:

* 1× ESP32-C6 SuperMini
* 3× TMC2209 modules
* 1× 0.91" I2C OLED
* 1× TP4056 Type-C module
* 1× XL6009 boost module
* 1× 1S LiPo battery
* 4× FSR sensors
* 3× micro linear bipolar stepper actuators
* 2× 100 kΩ resistors
* 4× 10 kΩ resistors
* 4× 1 kΩ resistors
* 3× 100 µF electrolytic capacitors
* 2× 470 µF electrolytic capacitors minimum, with one optionally up to 1000 µF
* 12× 100 nF ceramic capacitors
* 1× 10 µF capacitor
* headers / connectors as needed

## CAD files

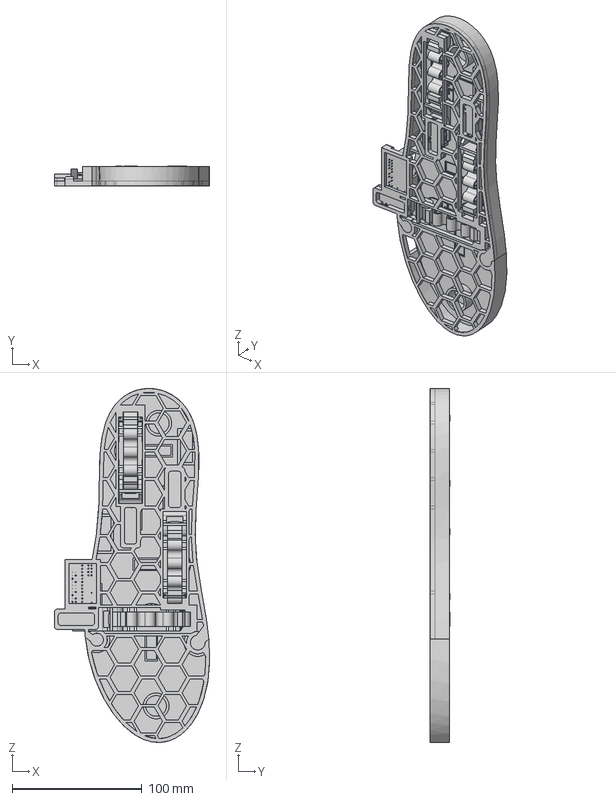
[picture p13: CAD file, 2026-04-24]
Exhibition Files and Photos/Product 3D Model.step
119.7 x 15.5 x 272.7 mm

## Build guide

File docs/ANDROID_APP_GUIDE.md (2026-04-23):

# Android App — Build & Install Guide

## What the app does

| Feature | Detail |
|---|---|
| BLE device | `EPD3DG6` |
| Service UUID | `4fa0c560-78a3-11ee-b962-0242ac120002` |
| Characteristic | `4fa0c561-78a3-11ee-b962-0242ac120002` (NOTIFY / READ) |
| Update rate | ~4 Hz |

The app connects over BLE and displays:
1. **Relative force** for FSR1, FSR2, FSR3 as animated colour/size circles + percentage bars  
   (green < 34 % → yellow < 67 % → red ≥ 67 %)
2. **Current mode** (DISCONNECTED / CONNECTED / MEASURING / ACTUATING / etc.)
3. **Battery percentage** (0–100 %)
4. **BLE connection status** dot (grey / yellow / green)

---

## Requirements

| Tool | Minimum version |
|---|---|
| Android Studio | Hedgehog (2023.1.1) or newer |
| Android SDK | API 35 (compile), API 26 (min — Android 8.0) |
| JDK | 17 (bundled with Android Studio) |
| Phone | Android 8.0+ with Bluetooth LE |

---

## Step 1 — Open the project

1. Launch **Android Studio**
2. `File → Open` → select the folder:
   ```
   EPD 3D G6/android_app/
   ```
3. Wait for Gradle sync to complete (first sync downloads ~500 MB of dependencies)

---

## Step 2 — Enable Developer Mode on your phone

1. **Settings → About phone** → tap **Build number** 7 times  
   *(exact path varies by manufacturer; search "Build number" in Settings)*
2. A toast will say **"You are now a developer"**
3. Go to **Settings → Developer options** → enable **USB debugging**

---

## Step 3 — Connect your phone and build

### Option A — USB (fastest)

1. Connect phone to PC via USB cable
2. Accept the **"Allow USB debugging?"** prompt on the phone
3. In Android Studio, select your phone from the device dropdown (top toolbar)
4. Click **▶ Run** (Shift+F10)
5. The app installs and launches automatically — done

### Option B — Build a release APK, then sideload

1. In Android Studio: **Build → Build Bundle(s) / APK(s) → Build APK(s)**
2. Gradle produces the file at:
   ```
   android_app/app/build/outputs/apk/release/app-release.apk
   ```
3. Transfer `app-release.apk` to your phone (USB, email, Google Drive, etc.)
4. On your phone:
   - Open **Settings → Apps → Special app access → Install unknown apps**
   - Grant permission to the app you used to receive the file (Files, Gmail, etc.)
5. Open the APK from your file manager and tap **Install**

---

## Step 4 — Grant Bluetooth permissions at first launch

On first launch the app will trigger a system permission dialog:

- **Android 11 and below:** Allow *Location* (required by system for BLE scanning)
- **Android 12+:** Allow *Nearby devices* (Bluetooth Scan + Connect)

Tap **Allow** (or **Allow while using app** on Android 12+).

---

## Step 5 — Connect to the device

1. Flash the firmware (see [FLASH_GUIDE.md](FLASH_GUIDE.md))
2. Power on the EPD 3D G6 board
3. Open the app and tap **CONNECT**
4. The app scans for a device named `EPD3DG6` (up to 10 s)
5. Once found it connects automatically and the display updates live

---

## Troubleshooting

| Symptom | Fix |
|---|---|
| "Device not found" | Make sure the ESP32 is powered and advertising; move phone closer (< 5 m) |
| "BLE permissions denied" | Go to **Settings → Apps → EPD 3D G6 → Permissions** and grant Nearby Devices / Location |
| App crashes on Android 11 | Ensure Location permission is granted (system requirement for BLE scanning) |
| Scan finds device but connection drops | Power-cycle the ESP32 and retry; avoid USB-3 ports near the phone |
| BATTERY shows — | Normal when not CONNECTED; check firmware is built with BLE enabled |
| FSR circles don't animate | Device is connected but no measurement has been taken; press the MODE button on the board to start a measurement cycle |

---

## Uninstalling

**Settings → Apps → EPD 3D G6 → Uninstall**

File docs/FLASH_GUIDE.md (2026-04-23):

# PlatformIO Flash Guide — EPD 3D G6

## Prerequisites

| Tool | Install |
|---|---|
| VS Code | https://code.visualstudio.com |
| PlatformIO IDE extension | VS Code → Extensions → search **PlatformIO IDE** |
| USB driver (Windows only) | ESP32-C6 SuperMini uses a **USB CDC** (native USB). Windows 10/11 includes the driver. If the port does not appear, install the [Silicon Labs CP210x driver](https://www.silabs.com/developers/usb-to-uart-bridge-vcp-drivers) or the [WCH CH340 driver](https://www.wch-ic.com/downloads/CH341SER_EXE.html) depending on the USB chip on your SuperMini board. |

---

## 1. Open the project

1. Launch VS Code.
2. **File → Open Folder** → select the firmware subfolder you want to flash:
   - `firmware/stepper_test/` — back-and-forth motion smoke test
   - `firmware/homing_test/` — blind homing sequence (retract → min, extend → 12 mm)
   - `firmware/main/` — full operational firmware with BLE, OLED, FSR, battery monitoring
   PlatformIO detects `platformio.ini` and automatically installs the **Espressif32** platform and toolchain on first open (takes 1–3 minutes).

> **Note — NimBLE first build:** `firmware/main/` depends on `h2zero/NimBLE-Arduino @ ^2.1.0`. The first build will download and compile the NimBLE library from scratch which can take **2–4 minutes** on first run. Subsequent builds use the cached library and are much faster.

> **Arduino IDE test sketch:** A minimal BLE server sketch for quick connectivity testing lives in `firmware/ARDUINO IDE APP TEST/sketch_apr14a/`. Open it directly in the **Arduino IDE** (not PlatformIO). You will need to install the following libraries via the Library Manager: **NimBLE-Arduino** (by h2zero) and **ArduinoJson** (by Benoit Blanchon).

---

## 2. Connect the board

1. Plug the ESP32-C6 SuperMini into your PC via USB-C.
2. Confirm the COM port appears:
   - **Windows:** Device Manager → Ports (COM & LPT) → look for *USB Serial Device* or *CP210x*.
   - **macOS/Linux:** `ls /dev/tty*` — look for `/dev/ttyACM0` or `/dev/ttyUSB0`.

> If PlatformIO cannot auto-detect the port, add the following line to `platformio.ini`:
> ```ini
> upload_port = COM3       ; Windows example
> ; upload_port = /dev/ttyACM0  ; Linux/macOS example
> ```

---

## 3. Enter boot / download mode (if required)

The SuperMini usually auto-resets into download mode. If the upload fails:

1. Hold the **BOOT** button on the board.
2. Press and release **RESET** while still holding **BOOT**.
3. Release **BOOT**.
4. Retry the upload immediately.

---

## 4. Build and upload

### Via VS Code UI

Click the **→ Upload** arrow in the PlatformIO toolbar at the bottom of the VS Code window.

### Via PlatformIO CLI (terminal)

```bash
cd firmware/stepper_test
pio run --target upload
```

A successful upload ends with output similar to:

```
Writing at 0x00010000... (100 %)
Hash of data verified.
Leaving...
Hard resetting via RTS pin...
```

---

## 5. Monitor serial output

After upload the board resets and prints motion status over USB.

### VS Code UI

Click the **plug icon** (Serial Monitor) in the PlatformIO toolbar.  
Baud rate: **115200**.

### CLI

```bash
pio device monitor --baud 115200
```

Expected output (stepper_test):

```
EPD 3D G6 — stepper back-and-forth test
  STEP pin : GPIO20
  DIR  pin : GPIO19
  ENN  pin : GND (hardwired on PCB)
Driver enabled. Starting motion...
→ Forward  (7680 steps)
← Reverse  (7680 steps)
→ Forward  (7680 steps)
...
```

Expected output (homing_test):

```
EPD 3D G6 — homing test
  STEP : GPIO20  DIR : GPIO19  ENN : GND (hardwired)
Homing: retracting to min extension...
Homed. Position = 0 (min extension)
Extending to max (18432 steps = 12mm, 1536 steps/mm)...
At max extension. Done.
```

Expected output (main firmware):

```
EPD 3D G6 — main firmware booting...
[ADC] VBAT raw sanity: 2217
[BLE] Advertising as EPD3DG6
System ready.
```

The `[ADC] VBAT raw sanity` value confirms the ADC attenuation is set correctly. A value near 0 means the attenuation is not applied and battery readings will be wrong.

---

## 6. Tuning motion parameters

### stepper_test

Edit the constants at the top of `src/main.cpp`:

| Constant | Current value | Effect |
|---|---|---|
| `STEPS_PER_MOVE` | `7680` | Steps per direction pass (~5 mm) |
| `STEP_DELAY_US` | `600` | Delay between pulses (lower = faster, ~1600 steps/s) |
| `STEP_PULSE_US` | `5` | Step pulse HIGH width (keep ≥ 1 µs) |
| `PAUSE_MS` | `500` | Pause between direction changes |

### homing_test

| Constant | Current value | Effect |
|---|---|---|
| `STEPS_PER_MM` | `1536` | Calibrated steps per mm |
| `STEPS_FULL_TRAVEL` | `18432` | Full 12 mm stroke (1536 × 12) |
| `STEPS_HOME_OVERSHOOT` | `22000` | Overdrive steps for guaranteed end stop contact |
| `STEP_HOME_DELAY` | `600` | Homing speed delay µs (~1600 steps/s) |
| `STEP_NORMAL_DELAY` | `300` | Extension speed delay µs (~3200 steps/s) |

After editing, re-upload with the **→ Upload** button.

---

## 7. Troubleshooting

| Symptom | Fix |
|---|-----|
| Port not found | Check USB cable, install/reinstall USB driver |
| Upload times out | Enter manual boot mode (step 3) |
| Motor does not move | Verify ENN is hardwired to GND on PCB; check VM (5 V) present on TMC2209 |
| Motor vibrates but no movement | Swap motor coil pair (OA1↔OA2 or OB1↔OB2) |
| Overheating driver | Reduce `STEPS_PER_MOVE` / increase `STEP_DELAY_US`; adjust current via trim pot |
| Battery shows 0% | `ADC_11db` attenuation must be set (already done in main firmware) |
| BLE device not found in app | Confirm firmware is advertising (`[BLE] Advertising...` in serial output); cycle BLE on phone |

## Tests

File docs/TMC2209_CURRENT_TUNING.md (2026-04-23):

# TMC2209 Current Limit Tuning Guide

The TMC2209 modules in this build run in **standalone STEP/DIR mode**.  
Current is set by adjusting the **VREF trim potentiometer** on each module — no UART required.

---

## How it works

The driver sets motor RMS current using this formula:

$$I_{RMS} = \frac{V_{REF}}{2.5 \times R_{SENSE}}$$

Most generic TMC2209 breakout modules use **R_SENSE = 0.11 Ω**, giving:

$$I_{RMS} = \frac{V_{REF}}{2.5 \times 0.11} = \frac{V_{REF}}{0.275}$$

| V_REF (V) | I_RMS (A) |
|---|---|
| 0.25 | 0.91 |
| 0.35 | 1.27 |
| 0.50 | 1.82 |
| 0.75 | 2.73 |
| 1.00 | 3.64 |

> Check your module's silkscreen or schematic for the actual R_SENSE value — some clones use 0.15 Ω or 0.22 Ω. The formula above still applies; just substitute the correct value.

---

## What you need

- Multimeter (DC voltage, mV range)
- Small flat-head screwdriver
- Motor connected and driver powered (5V_SYS on VM, 3.3V on VIO)
- ESP32 powered, `STEPPER_ENN` held LOW (drivers enabled) — flash a short sketch that just pulls GPIO7 LOW if needed

---

## Procedure

### 1. Locate VREF

On the TMC2209 module, VREF is the **wiper of the trim pot** — there is usually a small test pad labelled `VREF` next to the pot. If not, probe the centre pin of the potentiometer directly.

### 2. Reference GND

Place the negative probe on the **GND pad** of the module (not the motor coil pins).

### 3. Enable the driver

The driver must be powered and `ENN` must be LOW for VREF to be valid.

> From **v6.0 PCB onward, ENN is hardwired to GND on the PCB** — the driver is always enabled when powered. No firmware sketch is needed; simply power the system (5V_SYS present, ESP32 running).

### 4. Measure and adjust

- Power on the system (5V_SYS present, ESP32 running)
- Probe VREF with the multimeter
- Turn the pot **clockwise** to increase VREF (higher current)  
- Turn **counter-clockwise** to decrease VREF (lower current)
- Move slowly — the pot is sensitive; small turns = large change

### 5. Target value

For the **micro linear actuators** in this build, start conservatively:

| Recommendation | V_REF | I_RMS |
|---|---|---|
| Starting point | 0.30 V | ~1.1 A |
| Typical small actuator | 0.40–0.50 V | ~1.5–1.8 A |
| **Do not exceed** motor datasheet peak | — | check motor spec |

Set all three drivers to the same value unless the actuators differ.

---

## Verify with temperature check

Run the actuator for 30–60 seconds of continuous motion.  
After stopping, carefully touch the **driver IC** (the chip, not the pot):

- **Warm (< 50 °C)** — good
- **Hot but holdable** — acceptable, consider reducing by 0.05 V
- **Too hot to touch (> 70 °C)** — reduce VREF immediately; risk of thermal shutdown

TMC2209 has an internal thermal shutdown at ~150 °C but the modules have no heatsink — keep them well below that.

---

## Microstep setting (MS1 / MS2)

On standalone modules, microstep resolution is set by the **MS1 and MS2 pins**:

| MS1 | MS2 | Microsteps |
|-----|-----|---|
| LOW | LOW | 8 (default if floating) |
| HIGH | LOW | 2 |
| LOW | HIGH | 4 |
| HIGH | HIGH | 16 |

Most modules leave MS1/MS2 floating, which defaults to **8 microsteps**.  
If you change these, update `MAX_EXT_STEPS` in `firmware/main/src/main.cpp` to match the new steps-per-mm.

---

## Current hold reduction (IHOLD)

In standalone mode, TMC2209 automatically reduces hold current to **50% of run current** when the motor is idle (TPOWERDOWN default).  
This reduces heat when the actuators are extended and holding position. No firmware change needed.

---

## Repeat for all three drivers

Each TMC2209 has its own pot. Set them one at a time while the other two are disabled by physically removing them or probing individually. All three should end up at the same VREF unless your motors differ.

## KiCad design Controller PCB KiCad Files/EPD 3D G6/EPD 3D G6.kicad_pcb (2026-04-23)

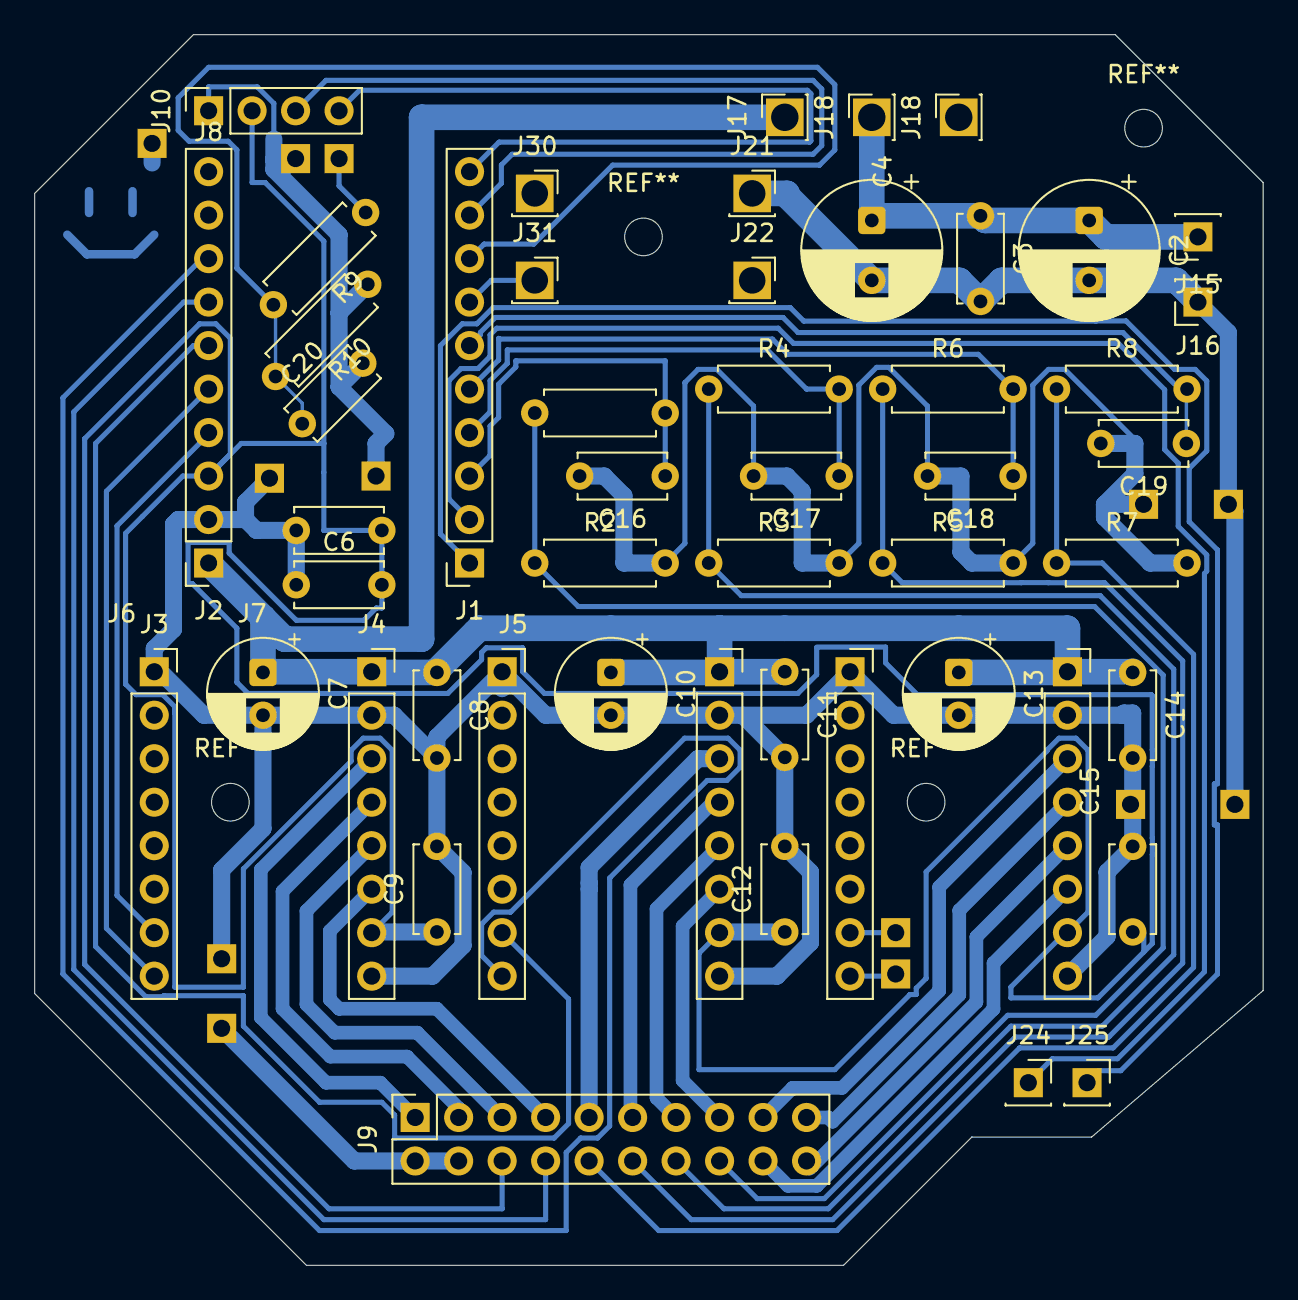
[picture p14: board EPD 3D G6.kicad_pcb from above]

Board: 2 copper layers, 71.8 x 71.9 mm, 50 parts (0 on the bottom side), 34 nets.

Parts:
C2, C4: 470uF; CP_Radial_D8.0mm_P3.50mm
C3, C6, C8, C9, C11, C12, C14, C15, C16, C17, C18, C19, C20: 100nF; C_Disc_D5.0mm_W2.5mm_P5.00mm
C5: 10uF; C_Disc_D5.0mm_W2.5mm_P5.00mm
C7, C10, C13: 100uF; CP_Radial_D6.3mm_P2.50mm
J1: J_ESP32_L; PinSocket_1x10_P2.54mm_Vertical
J2: J_ESP32_R; PinSocket_1x10_P2.54mm_Vertical
J3: TMC2209_1_L; PinSocket_1x08_P2.54mm_Vertical
J4: TMC2209_1_R; PinSocket_1x08_P2.54mm_Vertical
J5: TMC2209_2_L; PinSocket_1x08_P2.54mm_Vertical
J6: TMC2209_2_R; PinSocket_1x08_P2.54mm_Vertical
J7: TMC2209_3_L; PinSocket_1x08_P2.54mm_Vertical
J8: TMC2209_3_R; PinSocket_1x08_P2.54mm_Vertical
J9: 20 PIN TO INSOLE; PinSocket_2x10_P2.54mm_Vertical
J10: OLED; PinSocket_1x04_P2.54mm_Vertical
J15: BOOST_OUT+; PinSocket_1x01_P2.54mm_Vertical
J16: BOOST_OUT-; PinSocket_1x01_P2.54mm_Vertical
J17: PWR+; PinSocket_1x01_P2.54mm_Vertical
J18, J18#2: PWR-; PinSocket_1x01_P2.54mm_Vertical
J21: BTN3; PinSocket_1x01_P2.54mm_Vertical
J22: BTN4; PinSocket_1x01_P2.54mm_Vertical
J24: ACT3_DIR; PinSocket_1x01_P2.54mm_Vertical
J25: ACT3_STEP; PinSocket_1x01_P2.54mm_Vertical
J30, J31: BTN1; PinSocket_1x01_P2.54mm_Vertical
R1, R4, R6, R8: 1k; R_Axial_DIN0207_L6.3mm_D2.5mm_P7.62mm_Horizontal
R2, R3, R5, R7: 10k; R_Axial_DIN0207_L6.3mm_D2.5mm_P7.62mm_Horizontal
R9, R10: 100k; R_Axial_DIN0207_L6.3mm_D2.5mm_P7.62mm_Horizontal

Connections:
3V3: C5.2, C6.2, C9.1, C12.1, C15.1, J2.3, J4.7, J6.7, J8.7, J9.6, J10.VCC
5V_SYS: C2.1, C3.1, C4.1, C7.1, C8.1, C10.1, C11.1, C13.1, C14.1, J2.1, J4.1, J6.1, J8.1, J15.1, J17.1, J18.1
ACT1_DIR: J2.5, J3.8
ACT1_OA1: J4.4, J9.3
ACT1_OA2: J4.3, J9.1
ACT1_OB1: J4.5, J9.5
ACT1_OB2: J4.6, J9.7
ACT1_STEP: J2.4, J3.7
ACT2_DIR: J2.8, J5.8
ACT2_OA1: J6.E, J9.11
ACT2_OA2: J6.3, J9.9
ACT2_OB1: J6.5, J9.13
ACT2_OB2: J6.6, J9.15
ACT2_STEP: J2.6, J5.7
ACT3_DIR: J1.2, J7.8, J24.1
ACT3_OA1: J8.4, J9.19
ACT3_OA2: J8.3, J9.17
ACT3_OB1: J8.5, J9.20
ACT3_OB2: J8.6, J9.18
ACT3_STEP: J1.1, J7.7, J25.1
CONN_DETECT: J2.7, J9.8
FSR1: J9.16, R1.1, R2.1
FSR1_ADC: C16.1, J1.3, R1.2
FSR2: J9.14, R3.1, R4.1
FSR2_ADC: C17.1, J1.E, R4.2
FSR3: J9.12, R5.1, R6.1
FSR3_ADC: C18.1, J1.5, R6.2
FSR4: J9.10, R7.1, R8.1
FSR4_ADC: C19.1, J1.6, R8.2
GND: C2.2, C3.2, C4.2, C5.1, C6.1, C7.2, C8.2, C9.2, C10.2, C11.2, C12.2, C13.2, C14.2, C15.2, C16.2, C17.2, C18.2, C19.2, C20.2, J2.2, J3.ACT1_EN, J4.2, J4.8, J5.ACT2EN, J6.2, J6.8, J7.ACT3_EN, J8.2, J8.8, J9.2, J9.4, J10.GND (Pin_1_GND), J16.1, J21.1, R2.2, R3.2, R5.2, R7.2, R10.1
MODE_BTN: J1.7, J30.1, J31.1
OLED_SCL: J1.9, J10.OLED_SCL
OLED_SDA: J1.10, J10.OLED_SDA
VBAT_SENSE: C20.1, J1.8, R9.2, R10.2

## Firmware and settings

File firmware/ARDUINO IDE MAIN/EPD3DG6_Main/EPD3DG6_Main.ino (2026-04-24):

/**
 * EPD 3D G6 — Pumped Up Kicks V2
 * Full operational prototype firmware  |  Arduino IDE version
 * Hardware Reference v6.0
 *
 * ┌──────────────────────────────────────────────────────┐
 * │  State machine                                        │
 * │                                                       │
 * │  DISCONNECTED ──[plug in]───► CONNECTED              │
 * │  CONNECTED    ──[btn #1]────► MEASURING → MEASURED   │
 * │  MEASURED     ──[btn #2]────► ACTUATING → DONE       │
 * │  DONE         ──[btn #3]────► retract  ─► CONNECTED  │
 * │  any state    ──[unplug]────► DISCONNECTED            │
 * └──────────────────────────────────────────────────────┘
 *
 * BLE:
 *   Service UUID  : 4fa0c560-78a3-11ee-b962-0242ac120002
 *   Characteristic: 4fa0c561-78a3-11ee-b962-0242ac120002  (NOTIFY, READ)
 *   Payload (JSON): {"fsr1":<0-100>,"fsr2":<0-100>,"fsr3":<0-100>,
 *                    "mode":"<STATE>","snap":<0|1>}
 *   snap=0 → live FSR readings  (all states except ACTUATING / DONE)
 *   snap=1 → measurement snapshot (ACTUATING and DONE states)
 *   Notified every ~250 ms when a client is subscribed.
 *
 * ════════════════════════════════════════════════════════
 *  REQUIRED LIBRARIES
 *  Install via  Sketch > Include Library > Manage Libraries
 * ════════════════════════════════════════════════════════
 *  1. Adafruit SSD1306       by Adafruit    (^2.5.7)
 *     → automatically installs Adafruit GFX Library as a dependency
 *  2. NimBLE-Arduino         by h2zero      (^2.1.0)
 *
 * ════════════════════════════════════════════════════════
 *  BOARD SETUP  (Tools menu in Arduino IDE)
 * ════════════════════════════════════════════════════════
 *  Board Manager URL (add in File > Preferences):
 *    Espressif official:
 *      https://espressif.github.io/arduino-esp32/package_esp32_index.json
 *    OR pioarduino fork (recommended — better ESP32-C6 support):
 *      https://github.com/pioarduino/arduino-esp32/releases/download/3.1.3/package_esp32_index.json
 *
 *  Board:              ESP32C6 Dev Module
 *  USB CDC On Boot:    Enabled          ← REQUIRED for Serial over USB-C
 *  Flash Mode:         QIO
 *  Upload Speed:       921600
 *  Port:               (select the COM port for your ESP32-C6)
 *
 * Connector detect wiring:
 *   J_MAIN pin 1 (3V3_SENSE) ── 10 kΩ ──► GPIO15
 *   GPIO15 configured INPUT_PULLDOWN
 */

#include <Arduino.h>
#include <Wire.h>
#include <Adafruit_GFX.h>
#include <Adafruit_SSD1306.h>
#include <NimBLEDevice.h>

// ── Pin map (Hardware Reference v6.0) ───────────────────────────────────────────

static constexpr uint8_t PIN_FSR[4]  = {0, 1, 2, 3};   // ADC — FSR1–4
static constexpr uint8_t PIN_ENN     = 7;                // STEPPER_ENN shared (active LOW)
static constexpr uint8_t PIN_STEP[3] = {20, 16, 18};    // ACT1 ACT2(arch) ACT3(heel—dead, broken pad)
static constexpr uint8_t PIN_DIR[3]  = {19, 17, 14};    // ACT1 ACT2(arch) ACT3(heel—dead, broken pad)
static constexpr uint8_t PIN_SDA     = 7;                // OLED SDA — GPIO7 (hw ref v6.0)
static constexpr uint8_t PIN_SCL     = 6;                // OLED SCL — GPIO6 (hw ref v6.0)
static constexpr uint8_t PIN_BUTTON  = 4;               // INPUT_PULLUP, LOW = pressed (boot-safe)
static constexpr uint8_t PIN_CONN    = 15;              // INPUT_PULLDOWN, HIGH = connected (GPIO15)

// ── OLED (0.91" SSD1306 / SH1106 — I2C 0x3C) ────────────────────────────────

static constexpr uint8_t OLED_ADDR   = 0x3C;
static Adafruit_SSD1306  oled(128, 32, &Wire, -1);
static bool              gOledOk     = false;

// ── Motion parameters ────────────────────────────────────────────────────────

static constexpr uint32_t MAX_EXT_STEPS  = 21000;  // steps = full extension travel
static constexpr uint32_t STEP_DELAY_US  = 500;    // µs between step edges (3× cycle test speed)
static constexpr uint32_t STEP_PULSE_US  = 5;      // µs STEP pin HIGH width
static constexpr uint32_t ACT_STAGGER_MS = 75;     // delay between consecutive motor starts
static constexpr float    EXT_DEADBAND   = 0.08f;  // suppress negligible extensions

// ── ADC sampling ─────────────────────────────────────────────────────────────

static constexpr int ADC_SAMPLES = 7; // must be odd for clean median

// ── State machine ────────────────────────────────────────────────────────────

enum State : uint8_t {
    ST_DISCON,      // connector not present
    ST_CONN,        // connector present, idle — waiting for first button press
    ST_MEASURING,   // reading FSR channels
    ST_MEASURED,    // measurement stored — waiting for second button press
    ST_ACTUATING,   // driving actuators to computed targets
    ST_DONE,        // actuation complete — insole shaped, user disconnects to use
    ST_HOMING       // reconnected with actuators extended — retract before new cycle
};

static State   gState     = ST_DISCON;
static int32_t gPos[3]    = {};   // tracked position in steps from home (0 = retracted)
static int32_t gTarget[3] = {};   // computed target steps from last measurement
static float   gRelLoad[4]      = {};  // live normalised relative load fractions (sum = 1.0)
static float   gMeasuredLoad[3] = {};  // snapshot saved at end of doMeasure() — used during ACTUATING/DONE
static int     gLiveRaw[3]      = {};  // continuous single-sample live ADC reads for BLE display

// Minimum total raw ADC sum across all 3 FSRs to consider as real pressure.
// Below this, all live channels are shown as 0 (noise floor).
static constexpr int ADC_NOISE_FLOOR = 150; // per-channel floor — below this, channel reads 0

// Per-sensor full-scale ADC value (12-bit, 0–4095).
// Set each to the raw ADC reading you see in Serial Monitor when pressing FIRMLY on that FSR.
// Watch Serial Monitor (115200 baud) — it prints: [LIVE] r0=XXXX r1=XXXX r2=XXXX
static constexpr int FSR_SCALE[3] = {
    3,  // FSR0 = Metatarsal — raise if bar barely moves; lower if it maxes out too easily
    3,  // FSR1 = Arch       — stuck at 100% means this is too low; raise it
    3   // FSR2 = Heel       — too sensitive means this is too high; lower it
};

// ── BLE ───────────────────────────────────────────────────────────────────────

#define BLE_DEVICE_NAME  "EPD3DG6"
#define BLE_SVC_UUID     "4fa0c560-78a3-11ee-b962-0242ac120002"
#define BLE_CHAR_UUID    "4fa0c561-78a3-11ee-b962-0242ac120002"
#define BLE_CMD_UUID     "4fa0c562-78a3-11ee-b962-0242ac120002"  // WRITE — app→device

// BLE commands (single-byte)
#define CMD_BUTTON  0x01  // virtual button press
#define CMD_HOME    0x02  // force home all actuators
#define CMD_ESTOP   0x03  // emergency stop — disable drivers immediately

static NimBLECharacteristic* gBleChar     = nullptr;
static NimBLECharacteristic* gBleCmdChar  = nullptr;
static bool                   gBleConnected = false;
static uint32_t               gBleLastNotify = 0;

// Pending commands set from BLE write callback, consumed in loop()
static volatile bool gCmdButton = false;
static volatile bool gCmdHome   = false;
static volatile bool gCmdEstop  = false;

static const char* stateName(State s) {
    switch (s) {
        case ST_DISCON:    return "DISCONNECTED";
        case ST_CONN:      return "IDLE";
        case ST_MEASURING: return "MEASURING";
        case ST_MEASURED:  return "MEASURED";
        case ST_ACTUATING: return "ACTUATING";
        case ST_DONE:      return "DONE";
        case ST_HOMING:    return "HOMING";
        default:           return "UNKNOWN";
    }
}

class BleServerCallbacks : public NimBLEServerCallbacks {
    void onConnect(NimBLEServer*, NimBLEConnInfo&) override {
        gBleConnected = true;
        Serial.println("[BLE] Client connected");
    }
    void onDisconnect(NimBLEServer* server, NimBLEConnInfo&, int) override {
        gBleConnected = false;
        Serial.println("[BLE] Client disconnected — restarting advertising");
        server->startAdvertising();
    }
};

static void bleNotify() {
    if (!gBleChar) return;

    bool useSnapshot = (gState == ST_ACTUATING || gState == ST_DONE);
    const float* fsrSrc = useSnapshot ? gMeasuredLoad : gRelLoad;

    char buf[160];
    snprintf(buf, sizeof(buf),
        "{\"fsr1\":%d,\"fsr2\":%d,\"fsr3\":%d,"
        "\"live1\":%d,\"live2\":%d,\"live3\":%d,"
        "\"mode\":\"%s\",\"snap\":%d,"
        "\"act1\":%d,\"act2\":%d,\"act3\":%d}",
        (int)(fsrSrc[0] * 100.0f),
        (int)(fsrSrc[1] * 100.0f),
        (int)(fsrSrc[2] * 100.0f),
        gLiveRaw[0],
        gLiveRaw[1],
        gLiveRaw[2],
        stateName(gState),
        useSnapshot ? 1 : 0,
        (gState == ST_ACTUATING || gState == ST_DONE) ? (int)gPos[0] : 0,
        (gState == ST_ACTUATING || gState == ST_DONE) ? (int)gPos[1] : 0,
        (gState == ST_ACTUATING || gState == ST_DONE) ? (int)gPos[2] : 0);
    gBleChar->setValue((uint8_t*)buf, strlen(buf));
    gBleChar->notify();
}

class BleCmdCallbacks : public NimBLECharacteristicCallbacks {
    void onWrite(NimBLECharacteristic* c, NimBLEConnInfo&) override {
        auto val = c->getValue();
        if (val.size() == 0) return;
        uint8_t cmd = val[0];
        Serial.printf("[BLE CMD] 0x%02X\n", cmd);
        if      (cmd == CMD_BUTTON) gCmdButton = true;
        else if (cmd == CMD_HOME)   gCmdHome   = true;
        else if (cmd == CMD_ESTOP)  gCmdEstop  = true;
    }
};

static void setupBLE() {
    NimBLEDevice::init(BLE_DEVICE_NAME);
    NimBLEDevice::setMTU(185);
    NimBLEServer* server = NimBLEDevice::createServer();
    server->setCallbacks(new BleServerCallbacks());
    server->advertiseOnDisconnect(true);

    NimBLEService* svc = server->createService(BLE_SVC_UUID);
    gBleChar = svc->createCharacteristic(
        BLE_CHAR_UUID,
        NIMBLE_PROPERTY::READ | NIMBLE_PROPERTY::NOTIFY);
    gBleCmdChar = svc->createCharacteristic(
        BLE_CMD_UUID,
        NIMBLE_PROPERTY::WRITE | NIMBLE_PROPERTY::WRITE_NR);
    gBleCmdChar->setCallbacks(new BleCmdCallbacks());
    svc->start();

    NimBLEAdvertising* adv = NimBLEDevice::getAdvertising();
    adv->addServiceUUID(BLE_SVC_UUID);
    adv->setName(BLE_DEVICE_NAME);
    adv->enableScanResponse(true);
    adv->start();
    Serial.println("[BLE] Advertising as " BLE_DEVICE_NAME);
}

// ── Button debounce ───────────────────────────────────────────────────────────

static bool     gLastBtn     = HIGH;
static uint32_t gLastBtnTime = 0;
static constexpr uint32_t BTN_DEBOUNCE_MS = 30;

// ─────────────────────────────────────────────────────────────────────────────
// ADC helpers
// ─────────────────────────────────────────────────────────────────────────────

/** Insertion-sort median of ADC_SAMPLES reads on `pin`. */
static int medianADC(uint8_t pin) {
    int buf[ADC_SAMPLES];
    for (int i = 0; i < ADC_SAMPLES; i++) {
        buf[i] = analogRead(pin);
        delay(4);
    }
    for (int i = 1; i < ADC_SAMPLES; i++) {
        int k = buf[i], j = i - 1;
        while (j >= 0 && buf[j] > k) { buf[j + 1] = buf[j--]; }
        buf[j + 1] = k;
    }
    return buf[ADC_SAMPLES / 2];
}

// ─────────────────────────────────────────────────────────────────────────────
// Digital inputs
// ─────────────────────────────────────────────────────────────────────────────

/** True when J_MAIN connector is attached (GPIO15 pulled HIGH by 3V3_SENSE). */
static bool connPresent() {
    return digitalRead(PIN_CONN) == HIGH;
}

/** Returns true exactly once per button falling edge (with debounce). */
static bool btnEdge() {
    bool cur = (digitalRead(PIN_BUTTON) == LOW);
    uint32_t now = millis();
    bool edge = false;
    if (cur && !gLastBtn && (now - gLastBtnTime) > BTN_DEBOUNCE_MS) {
        edge = true;
        gLastBtnTime = now;
    }
    gLastBtn = cur;
    return edge;
}

// ─────────────────────────────────────────────────────────────────────────────
// Stepper motion
// ─────────────────────────────────────────────────────────────────────────────

/**
 * Send pulses on one stepper axis.
 * Positive steps = DIR HIGH (extend), negative = DIR LOW (retract).
 * dirInvert flips the physical DIR pin for axes wired in reverse.
 */
static void driveSteps(uint8_t sp, uint8_t dp, int32_t steps, bool dirInvert = false) {
    if (!steps) return;
    bool extend = (steps > 0) ^ dirInvert;
    digitalWrite(dp, extend ? HIGH : LOW);
    delayMicroseconds(2); // DIR setup time before first pulse
    uint32_t n = (uint32_t)abs((long)steps);
    for (uint32_t i = 0; i < n; i++) {
        digitalWrite(sp, HIGH); delayMicroseconds(STEP_PULSE_US);
        digitalWrite(sp, LOW);  delayMicroseconds(STEP_DELAY_US);
    }
}

/** Move actuator `idx` to absolute target steps from home. Updates gPos. */
static void moveToTarget(int idx, int32_t target) {
    // Set true for any axis whose DIR wiring is physically reversed.
    static constexpr bool DIR_INVERT[3] = {true, false, false}; // ACT1 flipped
    int32_t delta = target - gPos[idx];
    if (!delta) return;
    driveSteps(PIN_STEP[idx], PIN_DIR[idx], delta, DIR_INVERT[idx]);
    gPos[idx] = target;
}

/**
 * Enable drivers, retract all actuators to home sequentially, then disable.
 * Called after the user confirms reset in ST_DONE.
 */
static void retractAll() {
    digitalWrite(PIN_ENN, LOW);
    delay(10);
    for (int i = 0; i < 3; i++) {
        moveToTarget(i, 0);
        delay(ACT_STAGGER_MS);
    }
    digitalWrite(PIN_ENN, HIGH); // disable after fully retracted
}

// ─────────────────────────────────────────────────────────────────────────────
// OLED
// ─────────────────────────────────────────────────────────────────────────────

/**
 * Display up to 3 rows on the 128×32 OLED.
 * Uses content caching — only redraws when text changes.
 */
static void showOLED(const char* r1, const char* r2 = "", const char* r3 = "") {
    static char p1[33] = "\x01", p2[33] = {}, p3[33] = {};
    if (!gOledOk) return;
    if (!strcmp(p1, r1) && !strcmp(p2, r2) && !strcmp(p3, r3)) return;
    strncpy(p1, r1, 32); strncpy(p2, r2, 32); strncpy(p3, r3, 32);
    oled.clearDisplay();
    oled.setTextColor(SSD1306_WHITE);
    oled.setTextSize(1);
    oled.setCursor(0,  0); oled.print(r1);
    oled.setCursor(0, 11); oled.print(r2);
    oled.setCursor(0, 22); oled.print(r3);
    oled.display();
}

/** Row-3 status bar: "BLE:OK" — always shown with every state message. */
static void showOLEDWithStatus(const char* r1, const char* r2 = "") {
    char r3[22];
    snprintf(r3, sizeof(r3), "BLE:%s",
             gBleConnected ? "OK" : "--");
    showOLED(r1, r2, r3);
}

// ─────────────────────────────────────────────────────────────────────────────
// Mode 1 — Measurement
// ─────────────────────────────────────────────────────────────────────────────

static void doMeasure() {
    float raw[4];
    for (int i = 0; i < 4; i++) {
        raw[i] = (float)medianADC(PIN_FSR[i]);
    }

    float sum = raw[0] + raw[1] + raw[2] + raw[3];
    if (sum < 1.0f) sum = 1.0f;
    for (int i = 0; i < 4; i++) gRelLoad[i] = raw[i] / sum;

    for (int i = 0; i < 3; i++) {
        float ext = 1.0f - gRelLoad[i];
        if (ext < EXT_DEADBAND) ext = 0.0f;
        ext = constrain(ext, 0.0f, 1.0f);
        gTarget[i] = (int32_t)(ext * MAX_EXT_STEPS);
    }

    for (int i = 0; i < 3; i++) gMeasuredLoad[i] = gRelLoad[i];

    Serial.printf("[MEAS] raw=%.0f %.0f %.0f %.0f  "
                  "rel=%.3f %.3f %.3f %.3f\n",
                  raw[0], raw[1], raw[2], raw[3],
                  gRelLoad[0], gRelLoad[1], gRelLoad[2], gRelLoad[3]);
    Serial.printf("[MEAS] targets=%d %d %d steps  snapshot saved\n",
                  (int)gTarget[0], (int)gTarget[1], (int)gTarget[2]);
}

// ─────────────────────────────────────────────────────────────────────────────
// Mode 2 — Actuation
// ─────────────────────────────────────────────────────────────────────────────

static void doActuate() {
    digitalWrite(PIN_ENN, LOW);
    delay(10);

    for (int i = 0; i < 3; i++) {
        if (!connPresent()) {
            Serial.println("[ACT] Connector lost — aborting");
            digitalWrite(PIN_ENN, HIGH);
            return;
        }
        char msg[22];
        snprintf(msg, sizeof(msg), "ACT%d  %d steps", i + 1, (int)gTarget[i]);
        showOLEDWithStatus("ACTUATING...", msg);
        Serial.println(msg);
        moveToTarget(i, gTarget[i]);
        delay(ACT_STAGGER_MS);
    }
    delay(20);
    digitalWrite(PIN_ENN, HIGH);
    Serial.println("[ACT] Complete — drivers disabled");
}

// ─────────────────────────────────────────────────────────────────────────────
// Setup
// ─────────────────────────────────────────────────────────────────────────────

void setup() {
    Serial.begin(115200);
    delay(3000); // wait for USB CDC host to reconnect after reset
    Serial.println("EPD 3D G6 — boot");

    for (int i = 0; i < 3; i++) {
        pinMode(PIN_STEP[i], OUTPUT); digitalWrite(PIN_STEP[i], LOW);
        pinMode(PIN_DIR[i],  OUTPUT); digitalWrite(PIN_DIR[i],  LOW);
    }
    pinMode(PIN_ENN, OUTPUT);
    digitalWrite(PIN_ENN, HIGH); // drivers DISABLED at boot (safe default)

    pinMode(PIN_BUTTON, INPUT_PULLUP);
    pinMode(PIN_CONN,   INPUT_PULLDOWN);

    // ADC — 12-bit resolution, 11 dB attenuation for FSR channels (GPIO 0-3).
    analogReadResolution(12);
    analogSetAttenuation(ADC_11db);

    Wire.begin(PIN_SDA, PIN_SCL);
    gOledOk = oled.begin(SSD1306_SWITCHCAPVCC, OLED_ADDR);
    if (gOledOk) {
        oled.clearDisplay();
        oled.display();
    } else {
        Serial.println("OLED not detected — check SDA/SCL and address");
    }

    showOLED("EPD 3D G6", "Initializing...");
    delay(600);

    setupBLE();

    Serial.println("Ready");
}

// ─────────────────────────────────────────────────────────────────────────────
// Main loop (~20 Hz poll)
// ─────────────────────────────────────────────────────────────────────────────

void loop() {
    bool  conn = connPresent();
    bool  btn  = btnEdge();

    // ── BLE command handling (consumed once per loop) ─────────────────────
    if (gCmdEstop) {
        gCmdEstop = false;
        digitalWrite(PIN_ENN, HIGH);
        showOLEDWithStatus("E-STOP", "BLE command");
        Serial.println("[ESTOP] BLE emergency stop");
    }
    if (gCmdHome) {
        gCmdHome = false;
        if (gState != ST_HOMING && gState != ST_ACTUATING) {
            gState = ST_HOMING;
            Serial.println("[HOME] BLE triggered");
        }
    }
    if (gCmdButton) {
        gCmdButton = false;
        btn = true;
        Serial.println("[BTN] BLE virtual press");
    }

    // ── Connector removal — disable immediately, any state ───────────────────
    if (!conn && gState != ST_DISCON) {
        digitalWrite(PIN_ENN, HIGH);
        gState = ST_DISCON;
        Serial.println("[CONN] Removed");
    }

    // ── Connector re-attach ──────────────────────────────────────────────────
    if (conn && gState == ST_DISCON) {
        bool needsHome = false;
        for (int i = 0; i < 3; i++) if (gPos[i] != 0) { needsHome = true; break; }
        gState = needsHome ? ST_HOMING : ST_CONN;
        Serial.printf("[CONN] Attached — %s\n", needsHome ? "homing first" : "ready");
    }

    // ── State machine ────────────────────────────────────────────────────────
    switch (gState) {

        case ST_DISCON:
            showOLEDWithStatus("DISCONNECTED", "Attach connector");
            break;

        case ST_CONN:
            showOLEDWithStatus("CONNECTED", "Btn: measure");
            if (btn) gState = ST_MEASURING;
            break;

        case ST_MEASURING:
            showOLEDWithStatus("MEASURING...", "Hold still");
            doMeasure();
            gState = ST_MEASURED;
            break;

        case ST_MEASURED: {
            char l2[33];
            snprintf(l2, sizeof(l2), "r:%.2f %.2f %.2f",
                     gRelLoad[0], gRelLoad[1], gRelLoad[2]);
            showOLEDWithStatus("MEAS COMPLETE", l2);
            if (btn) gState = ST_ACTUATING;
            break;
        }

        case ST_ACTUATING:
            doActuate();
            gState = ST_DONE;
            break;

        case ST_DONE:
            showOLEDWithStatus("INSOLE SHAPED", "Unplug to use");
            break;

        case ST_HOMING:
            showOLEDWithStatus("HOMING...", "Retracting...");
            retractAll();
            gState = ST_CONN;
            Serial.println("[HOME] Complete");
            break;
    }

    // ── Continuous live FSR read (single sample, fast) ────────────────────
    if (gState != ST_ACTUATING && gState != ST_HOMING) {
        int raw[3] = {
            analogRead(PIN_FSR[0]),
            analogRead(PIN_FSR[1]),
            analogRead(PIN_FSR[2])
        };
        static uint8_t logTick = 0;
        if (++logTick >= 20) {
            logTick = 0;
            Serial.printf("[LIVE] r0=%4d r1=%4d r2=%4d  ->  live%%: %d %d %d\n",
                raw[0], raw[1], raw[2],
                constrain((raw[0] * 100) / FSR_SCALE[0], 0, 100),
                constrain((raw[1] * 100) / FSR_SCALE[1], 0, 100),
                constrain((raw[2] * 100) / FSR_SCALE[2], 0, 100));
        }
        for (int i = 0; i < 3; i++) {
            if (raw[i] < ADC_NOISE_FLOOR)
                gLiveRaw[i] = 0;
            else
                gLiveRaw[i] = constrain((raw[i] * 100) / FSR_SCALE[i], 0, 100);
        }
    }

    delay(50); // ~20 Hz main loop rate

    // ── BLE notify (~4 Hz) ───────────────────────────────────────────────
    uint32_t now = millis();
    if (gBleConnected && (now - gBleLastNotify) >= 250) {
        gBleLastNotify = now;
        bleNotify();
    }
}

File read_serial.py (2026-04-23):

import serial, time, sys

port = 'COM28'
baud = 115200
duration = 75  # seconds

try:
    ser = serial.Serial(port, baud, timeout=1)
except Exception as e:
    print(f"ERROR: {e}")
    sys.exit(1)

time.sleep(1)
print(f"Reading {port} at {baud} for {duration}s...\n")
sys.stdout.flush()

end = time.time() + duration
count = 0
while time.time() < end:
    try:
        line = ser.readline().decode('utf-8', errors='ignore').strip()
    except Exception as e:
        print(f"Read error: {e}")
        break
    if '[LIVE]' in line:
        print(line)
        sys.stdout.flush()
        count += 1

ser.close()
print(f"\nDone. Captured {count} LIVE lines.")

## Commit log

2026-04-01 Initial commit — hardware ref v4.1, operational firmware, LICENSE
    [EPD 3D G6.kicad_pcb, EPD 3D G6.kicad_sch]
2026-04-01 Add TMC2209 current limit tuning guide
2026-04-01 Add schematic framework (Phase A) - all 9 blocks, power rails, pin map, notes
    [EPD 3D G6.kicad_sch]
2026-04-01 Reorganise schematic global labels for clean left-to-right power/signal flow
    - Power rails (VBAT, 5V_SYS, 3V3) moved to top of each block (Y=12-36)
    - ESP32 Block 3: inputs left side Y=30-90 (10mm steps), outputs right Y=30-110
    - TMC blocks 4A/4B/4C: power+signals stacked top-to-bottom within each block band
    - FSR/VBAT_SENSE/OLED/UI labels spread across full block height (no clustering)
    - Fixed label shapes: Block 3 input pins now correctly use 'input' shape (were 'output')
    - 48 global labels total, all named nets connect correctly
    [EPD 3D G6.kicad_sch]
2026-04-01 Fix label positions: place all global_labels on block boundary edges
    Each label now sits exactly on its block's border (X=54/58/110/114/188/192/108/2)
    rather than floating in the middle of the sheet.
    - B1 VBAT output: right edge X=54
    - B2 VBAT in left X=58, 5V_SYS out right X=110
    - B3 ESP32: power at Y=9 top edge, 7 inputs on left X=114, 9 outputs on right X=188
    - B4A/4B/4C TMC: 5 inputs each on left X=192, distributed within Y bands
    - B5 FSR: 3V3 in left X=2, 4x FSR_ADC out right X=108
    - B6 VBAT sense: VBAT in left X=56, VBAT_SENSE out right X=108
    - B7 OLED: 3 inputs on left X=114
    - B8 UI: 2 outputs on right X=108
    [EPD 3D G6.kicad_sch]
2026-04-02 Update all docs and firmware to Electronics Reference v5.0
    GPIO changes (v4.1 -> v5.0):
    VBAT_SENSE: GPIO5 -> GPIO6
    STEPPER_ENN: GPIO4 -> GPIO7
    ACT1 STEP: GPIO6 -> GPIO20
    ACT1 DIR: GPIO7 -> GPIO19
    ACT2 STEP: GPIO12 -> GPIO18
    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
2026-04-02 Update connector J_MAIN pinout: pin 2 CONN_DETECT loopback detect, gitignore KiCad backups/cache
    [EPD 3D G6.kicad_sch]
2026-04-03 Add FIRMWARE_MAIN doc, rework state machine disconnect-to-use, remove fix_labels.ps1
    [EPD 3D G6.kicad_sch]
2026-04-03 Remove KiCad .history embedded repo from tracking
2026-04-03 Ignore KiCad .history folder
2026-04-07 Add homing_test firmware; tune stepper_test; update KiCad; update docs
    [EPD 3D G6.kicad_pcb, EPD 3D G6.kicad_sch]
2026-04-09 Add V2 PCB gerbers; remove kicad pcb from repo; update .gitignore
    [EPD 3D G6-B_Cu.gbl, EPD 3D G6-B_Mask.gbs, EPD 3D G6-B_Silkscreen.gbo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]
2026-04-13 Add V3 and V4 PCB gerber files
    [EPD 3D G6-B_Cu.gbl, EPD 3D G6-B_Mask.gbs, EPD 3D G6-B_Silkscreen.gbo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]
2026-04-13 docs: update pinout to v6.0 (ENN to GND, OLED SCL=GPIO6 SDA=GPIO7, VBAT=GPIO15, new J9 connector)
2026-04-13 docs: reassign CONN_DETECT to GPIO15, VBAT_SENSE to GPIO5 (ADC-capable)
2026-04-14 feat: add BLE telemetry to firmware and Android companion app
    - firmware/main: add NimBLE-Arduino BLE server
    - advertises as EPD3DG6
    - notifies JSON payload {fsr1,fsr2,fsr3,mode,batt} at ~4 Hz
    - fix PIN_VBAT=5, PIN_CONN=15 per hardware ref v6.0
    - android_app: new Kotlin/Compose BLE companion app
    - displays relative FSR forces (animated colour+size circles)
    - displays current mode and battery percentage
    - BLE connection status indicator
    - docs: add ANDROID_APP_GUIDE.md (build + sideload + permissions)
    [main.cpp]
2026-04-15 docs: update README, FIRMWARE_MAIN, FLASH_GUIDE for BLE, OLED status bar, ADC attenuation fix
    - README: add BLE section with UUIDs/payload, Android app quick-start, updated
    hardware table (NimBLE-Arduino 2.5.0), corrected state machine (HOMING state,
    DISCONNECTED flow), updated repo structure, design rules (ADC_11db note)
    - FIRMWARE_MAIN: add Section 8 (BLE - NimBLE 2.x API, setupBLE, JSON payload,
    globals, callback signatures), Section 9 (OLED status bar - showOLEDWithStatus,
    per-state table), update Section 5 (battery) with ADC_11db attenuation fix and
    analogReadResolution(12), renumber constants table to Section 10
    - FLASH_GUIDE: add NimBLE first-build time note, Arduino IDE tes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
    [EPD 3D G6-B_Cu.gbl, EPD 3D G6-B_Mask.gbs, EPD 3D G6-B_Silkscreen.gbo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]
2026-04-15 rebrand: Pumped Up Kicks -> Orthomate; firmware BLE snap field; Android app updates
    - README.md, Electronics Reference.txt: renamed product to Orthomate
    - firmware/main/src/main.cpp: add gMeasuredLoad[] snapshot saved at end of
    doMeasure(); bleNotify() sends snapshot during ACTUATING/DONE with snap=1,
    live gRelLoad during all other states with snap=0; updated JSON payload comment
    - android_app: Gemini-applied changes (Orthomate branding, snap field support,
    FSR snapshot display/storage, Gemini API analysis feature, updated BLE parsing)
    [main.cpp]
2026-04-22 Add Arduino IDE main firmware, KiCad files for controller and insole PCBs, reorganize PCB iterations, update main firmware and app assets
    [EPD 3D G6-B_Cu.gbl, EPD 3D G6-B_Mask.gbs, EPD 3D G6-B_Silkscreen.gbo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]
2026-04-24 Add exhibition media, update README with photos/PCB placement, fix GPIO table, update BOM, tighten .gitignore
    [Product 3D Model.step]
2026-04-24 Update PCB descriptions in README.md
